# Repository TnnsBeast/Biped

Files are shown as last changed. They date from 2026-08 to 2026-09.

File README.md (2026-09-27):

# Beni

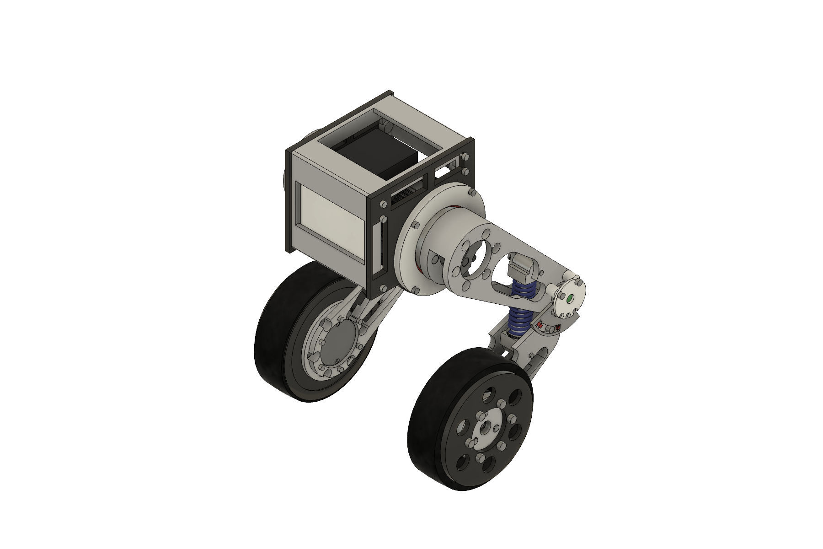
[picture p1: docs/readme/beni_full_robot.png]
Beni Prototype 1


A mostly 3D-printed wheeled biped moving to **Active-Knee Revision 2 (R2A)**:
active shoulder, remotely actuated belt-driven knee, and a driven wheel on each
leg. The current CAD gallery and assembled ABS leg show the legacy passive-knee
prototype. They remain the dimensional and failure-analysis baseline while the
new mechanism is designed.

**[Current status](PROJECT_STATUS.md)** · **[R2A plan](docs/design/active_knee_revision2_plan.md)** · **[Teardown evidence](evidence/reference/2026-09-25_beni_teardown/)** · **[Legacy mechanical design](beni_prototype1_design_record.md)** · **[Electronics](electronics/README.md)** · **[Firmware](firmware/README.md)** · **[Interactive viewer](web/)**

## Architecture direction

R2A removes the axial compression-spring cartridge. A knee actuator stays near
the shoulder/body and drives the knee through a synchronous belt inside the
proximal link. This keeps actuator mass out of the distal link and makes knee
angle, crouch, extension and landing response directly controllable.

The preferred Fusion study will compare a compact actuator mounted at the
proximal-link root with a stronger body-mounted actuator and shoulder-axis
jackshaft. The first layout uses one belt and is the simpler, lower-cost
prototype; the second keeps motor mass on the chassis. The actual knee motor,
belt family, ratio, output bearing stack and power architecture are not selected
yet. See the [dated actuator trade study](docs/design/active_knee_actuator_trade_study.md).
The project will not order or print around proportions inferred from the
teardown.

## Legacy mechanism and physical evidence

| Complete leg | Wheel motor and hub | Legacy passive knee |
|:---:|:---:|:---:|
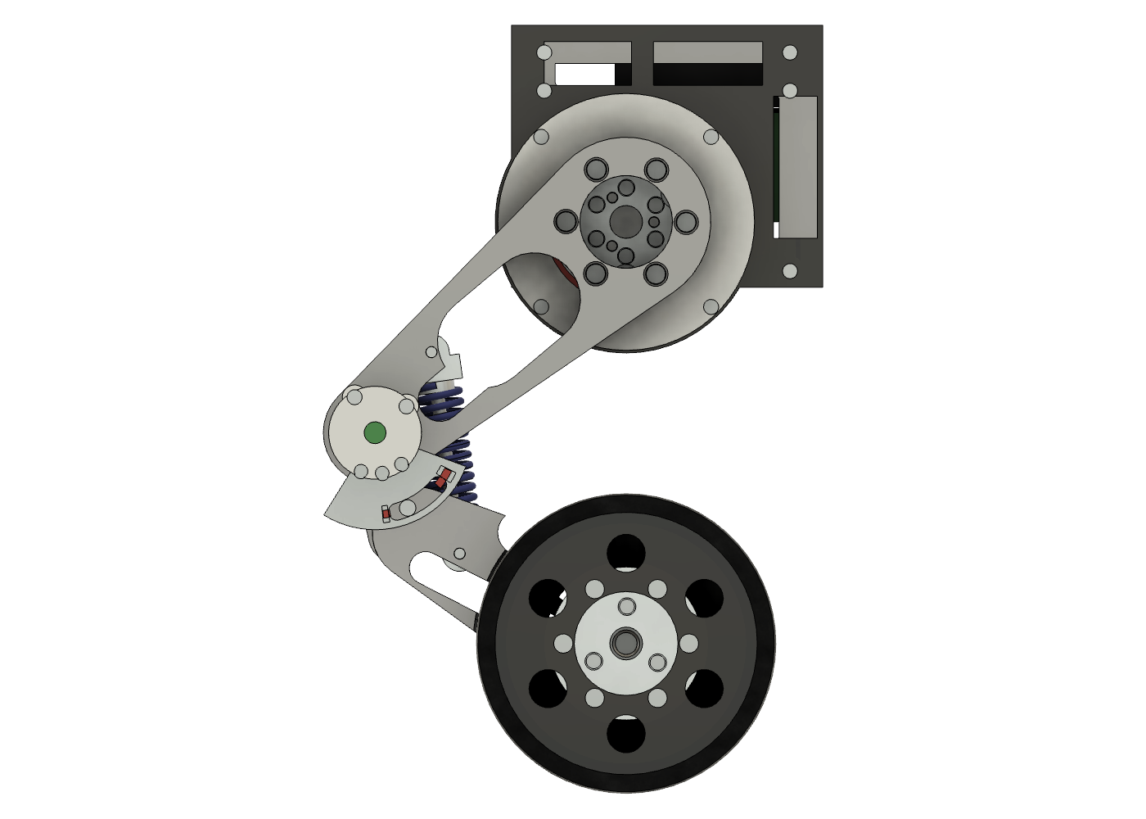
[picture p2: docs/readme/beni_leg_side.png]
Legacy complete Beni leg in Fusion
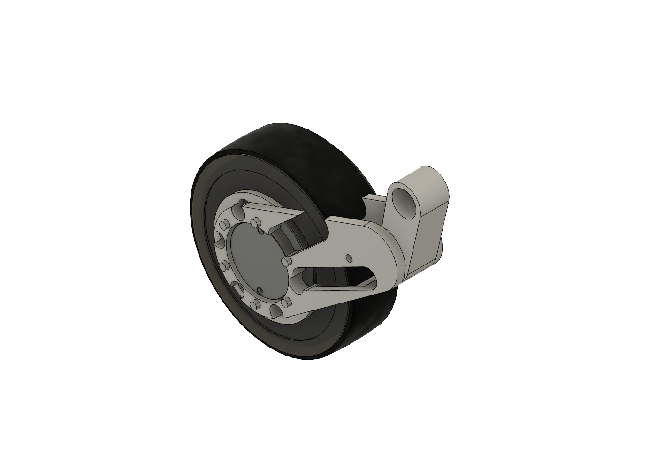
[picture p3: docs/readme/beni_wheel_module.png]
Wheel module with the motor housing fixed inboard and the output hub outboard
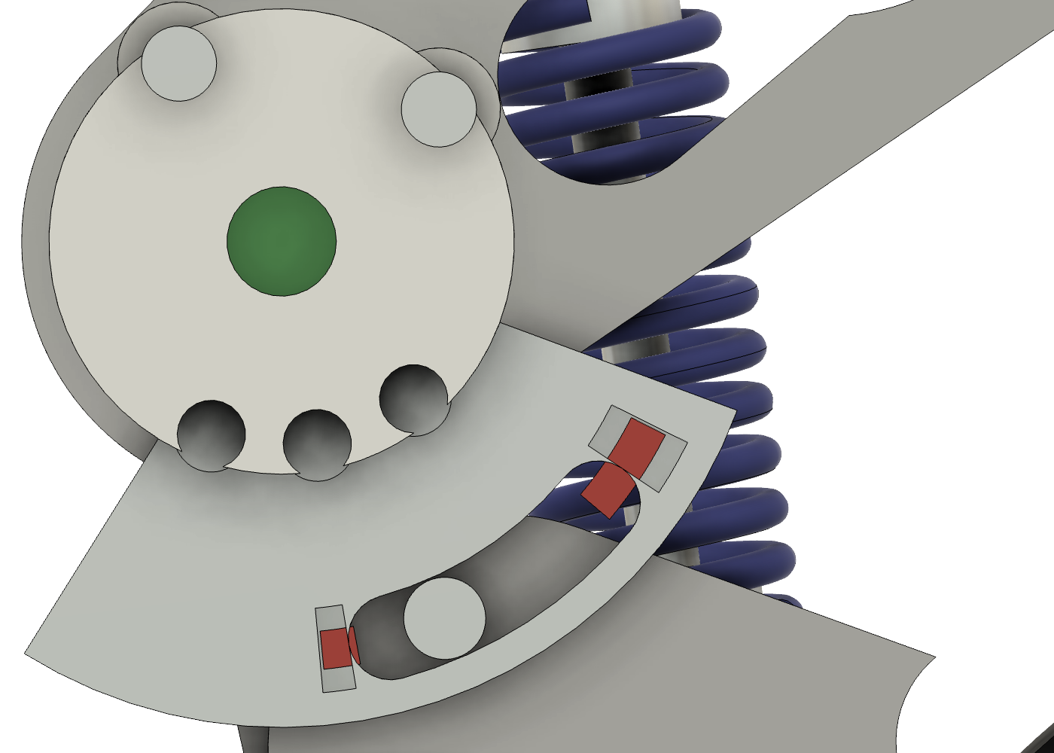
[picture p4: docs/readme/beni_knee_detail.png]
Legacy passive knee detail in Fusion
|  |  |  |

The owner printed and assembled the corrected shoulder hub, proximal link and
distal link. Most interfaces work, but the spring compresses on a curved path,
twists near both ends and escapes sideways. The unloaded guide is disengaged
and does not enter reliably during compression. Keep this article spring-free
and unpowered. The full observation is recorded in the
[failure evidence](evidence/assembly/2026-09-24_spring_escape/).

A frame review of the public teardown (September 27) shows Beni's knee driven
from the hip: a hip-coaxial crank moves the shin through a link, and a
body-fixed motor drives each hip ring through a short toothed belt. No belt runs
down the leg, so R2A's proximal-link belt is a project choice; comparing it with
a crank-and-link knee is an open decision. See the
[timestamped evidence note](evidence/reference/2026-09-25_beni_teardown/)
and the [R2A work plan](docs/design/active_knee_revision2_plan.md).

## Existing assembly references

The following documents describe the legacy article and remain useful for
accepted fit results, hardware inventory and assembly-path lessons:

- [Illustrated passive-article assembly manual](docs/assembly/ordered_pin_picture_guide.md)
- [Shoulder close-up](docs/assembly/shoulder_to_proximal_link.md)
- [Heat-set receiver picture map](docs/assembly/heatset_receiver_map.md)
- [Assembly verification gate](ASSEMBLY_VERIFICATION.md)
- [First-article evidence and archived print files](first_article_stl/README.md)
- [Manufacturing constraints](MANUFACTURING_CONSTRAINTS.md)

The CAD gallery is exported from the live Fusion model with
[`readme_images_fusion.py`](readme_images_fusion.py). It must be refreshed only
after a verified R2A Fusion model changes the displayed robot, leg, wheel or
knee views.

---

<!-- PRINT_QUEUE_START -->
## Current print queue — no R2A parts released

Automatically maintained convenience section for the active build.

**Do not print another passive-knee spring part.** No Active-Knee Revision 2
part or STL has been released. The next printable item will be an unpowered ABS
belt-transmission article after the motor layout, belt and pulley family, knee
output stack, service path and print orientation pass the Fusion release gates.

Keep the assembled legacy article spring-free and unpowered. Retain its parts,
owned actuators, bearings, pins and fasteners as evidence and possible reusable
hardware until the R2A BOM identifies them explicitly.
<!-- PRINT_QUEUE_END -->

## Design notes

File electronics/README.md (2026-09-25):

# Beni Prototype 1 — Electronics Design

**Revision 0 — 2026-08-09.** Originally written against
`beni_electronics_handoff_brief.md` §10. **That file no longer exists**: its
CAD-derived geometry survives as `00_mechanical_datum.md`, and its
request-for-design content is now answered by `01`–`07` themselves. Read §10
references below as pointing at `00_mechanical_datum.md`.
**[LEGACY FOR R2A]** The mechanical side described here was frozen and audited
for the four-actuator passive-knee robot. Active-Knee Revision 2 adds one knee
actuator per leg and invalidates the motor count, power budget, CAN topology,
harness, mass model and jump/landing controller. Use these documents as a
baseline only; do not place a new robot order until the knee motor and belt
ratio are selected in the
[R2A plan](../docs/design/active_knee_revision2_plan.md).

Every number here is traceable to either the CAD/design record (trusted), vendor
documentation (marked), or a calculation shown in-line (reproducible). Where a
figure could not be confirmed it is marked **[UNVERIFIED]** and appears in
`05_open_questions.md`. Do not order parts against an unverified figure.

## Reading order

| File | Covers | Brief §10 deliverable |
|---|---|---|
| `README.md` (this) | Decisions, §3 blockers, architecture | — |
| `01_power_and_battery.md` | Pack, power tree, budget, safety, regen | 1, 6, 7 |
| `02_harness_and_routing.md` | Clock spring, satellite node, connectors | 3, 4 |
| `03_compute_and_can.md` | Controller, IMU, CAN topology | 2, 5 |
| `04_firmware.md` | Plant model, LQR gains, jump/landing FSM, estimation | 8 |
| `05_open_questions.md` | Blockers, supplier questions, change requests | 10 |
| `06_logging_and_bringup.md` | Logging pipeline, 7-stage bring-up with gates | 9 |
| `07_bom.md` | Priced shopping list, ordered in three waves | — |

## The three §3 blockers — resolved

The brief says to resolve these before designing anything downstream. All three
now have answers, and **all three overturned an assumption baked into the BOM.**

### §3.1 Battery voltage — the brief blamed the wrong actuator

The brief assumed the GIM6010-8 shoulder sets the voltage ceiling. It does not.
The GIM6010-8 is a wide-input part (sources give 12–56 V, 15–60 V, or 12–72 V —
see `05_open_questions.md`). **The GIM4305-10 wheel actuator is the binding
constraint**: its SDC101 driver installation guide gives **12–36 V**, while
marketing copy claims 12–48 V and some reseller tables say 12–24 V.

The BOM's 4S pack (14.8 V nom) is too low regardless — a 4S pack cannot drive a
24 V-class actuator at rated performance, and the jump is power-limited.

**Decision: 6S LiPo (22.2 V nominal / 25.2 V full), with a 20 V buck feeding the
two wheel drivers.** The buck costs ~15 g and is deleted if Steadywin confirms
the 36 V rating in writing. This is the only option that is safe under *both*
the 24 V and the 36 V reading of the spec. See `01_power_and_battery.md` §2.

### §3.2 Battery physical size — cylindrical cells are out, and Z must open up

The CAD envelope is 69 × 25 × 45 mm = 77.6 cm³ at 250 g. A standard 4S 2200
LiPo is ~105 × 34 × 30 mm and 105 mm does not fit anywhere in the chassis.

Cylindrical cells fail on both axes: 6 × Molicel P26A 18650 is 275 g bare (over
the 250 g budget before assembly) and the 28 mm Z limit means the top-forward
box takes exactly **one** 18650. You need six and you can site two.

**Decision: GNB 6S 550 mAh "long type" (GNB5506S100AHV), 36 × 18 × 71 mm, 82 g,
12.2 Wh.** Near-exact match to the 36 × 28 × 72 mm top-forward box. It is a
**LiHV** pack — charge to 4.20 V/cell as ordinary LiPo, never 4.35 V.

Runtime is honest but short: ~18 min standing, ~10 min driving, ~13 min mixed.
**The single highest-value mechanical change available is opening chassis Z from
28 to 40 mm**, which allows 6S2P (2 packs, 164 g, 24.4 Wh) — double the runtime
and half the C-rate stress, still inside the mass budget. See `05_open_questions.md`.

### §3.3 Harness conductor count — the cavity constraint was misread

The brief treats the clock-spring cavity's 4.0 mm axial height as a *thickness*
limit and reasons about FFC. **It is a width limit.** In a clock spring the
bending curvature points radially, so bending strain is set by *radial*
thickness (12 mm available); the 4.0 mm axial dimension is the ribbon **width**
(~3.4 mm usable after slip sheets). A 20-way 1.0 mm-pitch FFC is 20+ mm wide and
cannot fit. At 3.4 mm you get 3 ways at 1.0 mm pitch or 6–7 at 0.5 mm.

**Decision: a satellite CAN node on the proximal link**, which drops the crossing
conductor count from 7–10 to **four** — V+, V−, CAN_H, CAN_L. The AS5048A then
runs full-rate SPI over a 40 mm PCB trace instead of 700 mm of cable next to a
motor. See `02_harness_and_routing.md`.

**Also corrected: the clock-spring wrap margin in the design record is wrong.**
§4.3 claims ~470° capacity / 27% margin from 400 mm of cable. Recomputing:

```
Δθ = L·(r_o − r_i) / (2π·r_i·r_o) = 400 × 11 / (2π × 20.5 × 31.5) = 1.084 turns = 390°
```

Against a 370° requirement that is **20° / 5% margin, not 27%.** Specify
**470–500 mm** of free spiral.

## Legacy system architecture [SUPERSEDED FOR R2A]

```
         6S LiPo 22.2V ──┬── fuse 30A ── P-FET soft-start ── XT30 loop key
                         │
              ┌──────────┼──────────────┬──────────────────┐
              │          │              │                  │
        shoulder L   shoulder R    20V buck ──┬── wheel L   │
        GIM6010-8    GIM6010-8               └── wheel R    │
              │          │                    │        │    │
          [CAN bus A: ODrive CANSimple]   [bus B]  [bus C]  │
              └────┬─────┘                    │        │    │
                   │                          │        │    │
              MAIN BOARD (STM32G474RET6, 84 × 60 × 1.0 mm, centre slot)
                   │                          │        │
                ICM-42688-P IMU        satellite L  satellite R
                                       (STM32G0B1 + AS5048A, proximal link)
```

**Three CAN buses, not one.** This falls out of two independent constraints that
happen to agree:

1. **Protocol.** The two actuators do not speak the same protocol. The GIM6010-8
   is an ODrive CANSimple derivative (`ID = node_id<<5 | cmd_id`); the
   GIM4305-10's SDC101 runs a proprietary "SteadyWin" or MIT protocol with its
   own master-ID scheme. Mixing them on one bus is possible but miserable.
2. **Bandwidth.** A single 1 Mbit classical bus cannot carry 4 nodes at 1 kHz —
   94% load typical, **108% worst-case** with bit stuffing. Neither actuator
   supports CAN-FD, so the FD escape hatch is closed.

The split — **A = both shoulders, B = left wheel + left satellite, C = right
wheel + right satellite** — lands every bus at 35–47% load, keeps each protocol
on its own wire, and matches the three FDCAN peripherals on an STM32G474RET6
exactly. It also means each clock spring carries only *its own* leg's bus, so
the 4-conductor crossing works with no sharing.

## Standing decisions

| Area | Decision |
|---|---|
| Bus voltage | 6S LiPo, 25.2 V full; 20 V buck for wheel drivers |
| Pack | GNB 6S 550 mAh long type, 82 g (2P if Z opens to 40 mm) |
| Controller | Custom 84 × 60 × 1.0 mm 4-layer, STM32G474RET6 |
| IMU | ICM-42688-P, 8 kHz ODR, AAF 250–500 Hz, decimate to 1 kHz *(rig: on-hand BNO085, **1 kHz raw** — it cannot stream 8 kHz)* |
| CAN | 3 × classical 1 Mbit, TCAN3414 transceivers *(rig: 2 × 500 kbps on Adafruit CAN Pal 5708 — TJA1051T/3, 3.3 V)* |
| Knee sensing | AS5048A on a satellite STM32G0B1CBT6 node, per leg |
| Control rate | 1 kHz (500 Hz floor) |
| E-stop | XT30 loop key (primary) + fail-safe soft stop + windowed WDT |
| Estimated mass | ~118 g against a 120 g budget — no margin |

## Four numbers in the brief that are wrong

Found while deriving the control design from `sim/beni.urdf` and
`sim/beni_inertia.json`. Full working in `04_firmware.md` §1.

| Brief | Actual |
|---|---|
| Unstable pole 9.7 rad/s | **11.20 rad/s** (τ = 89 ms). The LIPM formula drops body pitch inertia and the wheel reaction torque. |
| A 100 mm drop has ~10% energy margin on the knees | **It bottoms out.** The brief omits gravity work during the 50 mm of compression: 4.85 J demand vs 3.55 J capacity. Passive limit is ~49 mm for the two-leg robot (spring-rate method); the single-leg rig's 2-DOF figure is **45 mm** planning / **46.3 mm** at +24° (`../beni_single_leg_rig_design_record.md` §3). |
| Clock spring: 27% wrap margin | **5%** (§3.3 above). |
| Shoulders control ride height | **dRide/dθ_s = 0 at the nominal pose.** Zero height, damping and CBF authority at θ_s = 0. Fixed by a scissor stance. |

Consequence for the test plan: the brief's gate *"no powered jump until a 100 mm
drop never reaches +27°"* **cannot be passed passively.** It is replaced with a
49 mm passive gate plus a 100 mm gate run with the shoulder landing controller
live — see `06_logging_and_bringup.md` Stage 5, which now states the gate as
45 mm (the rig's planning limit).

Two further findings that are not brief errors but change the design:

- **The IMU datum pad is 195 mm above the wheel axis** — the worst location on
  the robot. At 20 rad/s² of pitch acceleration the lever arm produces 22° of
  apparent tilt against a 0.1° budget. Move it (CR-9).
- **A leg bounce mode at 3.66 Hz sits only 2.05× above the balance pole**, with
  ζ ≈ 0.01. Active shoulder damping is mandatory, not optional. *(3.66 Hz is the
  two-leg robot's 1-DOF figure. For the single-leg rig it is superseded: the rig
  is 2-DOF and predicts **3.49–3.63 Hz** — `../beni_single_leg_rig_design_record.md`
  §3.1.)*

## Status

All ten §10 deliverables are drafted across `01`–`06`. **They describe the
legacy four-actuator two-leg robot.** The legacy Mode A rig used a Teensy 4.1,
20 V bench supply and breadboarded buses; its carve-outs remain marked in `01`,
`02`, `03` §3, `06` and `07` Wave 0. R2A is the active design and requires a
fresh six-actuator electronics pass after knee-motor selection.

**Amended 2026-08-17 — the rig build is MODE A only.** The vertical slide, the
ballast and the drop series are deferred, which changes three things on the
electrical side:

| Change | Where |
|---|---|
| **Brake chopper [DEFERRED — MODE B]** — resistor, TLV3011, MOSFET, freewheel diode, sense divider **and heatsink** all out of Wave 0. Nothing generates regen with no drops. ⚠ Until it exists, **nothing may backdrive a motor** | `01` §7.2, `07` Wave 0 |
| **IMU gate re-scoped 8 kHz → 1 kHz raw** — the on-hand BNO085 tops out near 1 kHz on the SH-2 raw gyro report (100 Hz for calibrated/uncalibrated gyro), and its on-chip fusion carries 6.6 ms of latency, which alone would blow the <8 ms loop gate. Read raw, fuse on the Teensy | `06` Stage 0, `03` §4 |
| **Transceiver is the Adafruit CAN Pal 5708** (TJA1051T/3, onboard charge pump, single 3.3 V rail) — the TCAN3414 is surface-mount and this build is breadboarded. One board per bus | `07` Wave 0 |

**Owner scope 2026-09-02:** the complete single-leg integration article remains
ABS. Stages 0–1 and the wheel-clear/current-limited, self-weight-only subset of
Stage 2 are active, including unloaded phase-resistance, latency and CAN-soak
checks. The lever torque sweep, main-spring preload and
characterisation, ground traction, stall/proof loading, Stage 5 drops and all
later dynamic gates move to the two-leg PA-CF structural build. The detailed
boundary is in `06_logging_and_bringup.md`.

Nothing here has been
built or measured: every power figure is an estimate pending an inline watt
meter, the peak-power number swings ±40% on an unverified phase resistance, and
the wheel driver's maximum bus voltage — the one answer that decides the pack —
is still outstanding with Steadywin. **Read `05_open_questions.md` before
ordering anything.**

The shopping list is in `07_bom.md`. **Wave 0 (the Mode A rig) is now ~$25 of
electronics** plus a bench PSU; Wave A is ~$310 of two-leg dev hardware, and
Wave B is blocked on Steadywin.

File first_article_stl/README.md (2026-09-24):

# First print — actuator fit gates (ABS)

The four base files in [`actuator_fit/`](actuator_fit/) are the nominal
STEP-to-real-hardware gates printed on 2026-08-22.  Their results route the next
prints below.  The Mode A cable anchor in [`mode_a/`](mode_a/) is validated too,
but it is not needed to pass the motor-fit gate.

## Batch 1: printed and tested 2026-08-22

| STL | Checks |
|---|---|
| `ABS_FIT_GIM6010_HOUSING.stl` | shoulder housing clearance and 8 × M3 PCD74 clocking |
| `ABS_FIT_GIM6010_OUTPUT.stl` | shoulder output M3 pattern and the three Ø4 locating pins |
| `ABS_FIT_GIM4305_HOUSING.stl` | wheel-motor driver-cover clearance and 6 × M2.5 pattern |
| `ABS_FIT_GIM4305_OUTPUT.stl` | wheel output M3 pattern and Ø37.3 × 0.8 register pocket |

Owner-reported result: GIM6010 housing PASS; GIM6010 output pattern aligned but
its Ø4.05 printed pin bores did not hand-fit; the follow-up Ø4.15 pin-bore
coupon PASSed with a light press; GIM4305 housing PASSed with the real M2.5
screws; GIM4305 output PASS. The GIM4305 coupons are standalone, opposite-face
interface gauges and are not intended to nest. The failed GIM6010 output coupon
remains the evidence for the failed Ø4.05 result.

These were built and exported from Fusion document
`Beni_Prototype1_TestGauges` through the Fusion MCP.  Fusion's exact B-Rep
validation and source dimensions are in
[`actuator_fit/fusion_manifest.json`](actuator_fit/fusion_manifest.json).
Independent binary-mesh inspection found one closed manifold shell per file,
zero open/non-manifold edges, and zero degenerate triangles.

## Batch 1B: GIM6010 output-pin clearance diagnostic

The three generated files in
[`actuator_fit/gim6010_pin_trials/`](actuator_fit/gim6010_pin_trials/) retain the
validated three-pin pattern and change only the printed pin-bore diameter:
Ø4.15, Ø4.20 and Ø4.25 mm. The
[diagnostic README](actuator_fit/gim6010_pin_trials/README.md) gives the print
order, identification marks and pass rule. These are ABS calibration values,
not released PA-CF dimensions.

The Ø4.15 coupon passed on 2026-08-22, so stop there; the larger two trials are
not needed. Batch 2 is the unloaded ABS shoulder assembly in
[`assembly_dry_fit/`](assembly_dry_fit/). The original hub print proved the
motor interface but predated heat-set receiver design. Its replacement now
retains Ø4.15 and uses the owner-passed Ø5.3 M4 × 8 receivers. The owner has
printed it and successfully installed its inserts. The corrected proximal link
is printed and the owner confirmed all six hub screw seats on September 7.
The same folder contains
bed-ready shoulder-plate and cable-cover articles.

## 2026-09-04 owned-insert release

The owner confirmed the largest M4 × 8 ladder station, Ø5.3, passed all
installation and cooled-retention checks. Fusion incorporated it in both
saved documents. The two hubs and cable cover retain bed-ready ABS files in the
[receiver manifest](heatset_receiver_release_manifest.json). On September 14,
the owner selected Ø4.5 on the dedicated M3 ladder; the manifest, shoulder
plate, proximal link and stand exports now reflect that result.

The owner accepted the corrected hub's insert installation on 2026-09-05.
The **access-fixed Ø19.15 proximal link is printed with six-screw seating accepted**; use the final
[README print queue](../README.md#current-print--ordered-pin-unpowered-abs-mechanical-article). Two head
paths and one incomplete seat were corrected. The front cable post also now
mounts outside the cover. The final tyre-compatible wheel rim retains its
printability hold; the later no-tyre mechanical-test shell is separate.
[Current audit and acceptance](../evidence/assembly/2026-09-05_access_fix/).

## 2026-09-06 supported knee mock-up

The [temporary pin and provisional distal link](knee_mockup/) are printed and
provisionally assembled by owner report on September 7. Both spring caps are
also printed, with both spring ends seating flat uncompressed. Supported knee
movement and pin removal pass. [Photo and physical acceptance scope](../evidence/assembly/2026-09-07_owner_mockup/).
On September 15, the owner inserted a received metal pin into that provisional
shin. Its nominal Ø10 bore seized the pin, and the shin was broken to recover
it. The earlier loose Ø9.7 printed-pin result remains evidence, but the shin is
destroyed and must not be reprinted for another steel-pin trial. [Steel-pin
result](../evidence/knee_fit/2026-09-15_steel_pin_provisional_shin/).
The traveller remains scoped to two detached links supported on the bench;
the caps check the ends of the owned spring off the leg. Follow that batch's specific support
policy: **the distal mock-up needs selective supports**, while the pin and
caps print without supports. No main spring or motors attach to this mock-up.

## 2026-09-16 steel knee-pin bore result — Ø10.30 ABS selected

One received metal pin seated through both installed bearings and seized in the
provisional shin's nominal Ø10 ABS bore. The provisional shin was broken to
recover it. The owner printed the initial Ø10.05–Ø10.25 ladder
and found nominal Ø10.25 gives the intended firm-thumb fit through its 19.0 mm
station. The owner selected nominal Ø10.30, one 0.05 mm step above the physical
result, while the receiver was expected to span 21.6 mm. Fusion's final service
audit found that copied sleeve span trapped the link inside the bearing pockets,
so v26 confines the receiver to the clear 20.0 mm fork gap with 0.8 mm axial
clearance per side. Print the [released bed-ready distal fit article](assembly_dry_fit/ABS_FA_Distal_Link_L_D10p30_STEEL_PIN_FIT_PRINT_ORIENTED.stl)
and complete its physical insertion, withdrawal, spin, rock and axial-play
checks. The [21.6 mm full-span ladder](knee_pin_fit/) remains a conservative
optional diagnostic. Retention and encoder coupling still gate powered use.

## 2026-09-14 M3 receiver recalibration — Ø4.5 selected

The owner has printed the cable cover, corrected front cable post, wheel hub
and general fit gauge. [Exact files and completion record](../evidence/assembly/2026-09-07_small_parts_printed/).
The gauge's nominal Ø4.0 M3 station is too small.
[Physical result](../evidence/inserts/2026-09-14_m3_coupon_fail/). The owner
printed the Fusion-generated [Ø4.1–4.5 M3 ladder](insert_fit/) and selected the
largest, unmarked-end station, nominal Ø4.5. The active sources and exports were
promoted and verified through Fusion. Print the Ø4.5 corrected proximal-link
replacement and stand; print the Ø4.5 shoulder plate if the fitted plate is the
prior Ø4.0 revision. Detached motor-fit and cover/post/harness results are still pending;
the rear anchor is optional.
The [current print queue](../README.md#current-print--ordered-pin-unpowered-abs-mechanical-article) contains
the remaining prints, and [PROJECT_STATUS.md](../PROJECT_STATUS.md) maintains
the active mechanical, CAD and electronics work.

## 2026-09-17 unpowered spring-mechanical article

The new [mechanical spring test batch](mechanical_spring_test/) adapts the owned
OD18 / ID9 / 50 mm spring with two Ø8-pilot eyes, a removable square guide,
a -8°…+15° stop, an outboard steel-pin spacer/keeper and a support-free no-tyre
wheel shell. All seven STLs are print oriented and Fusion verified. The spring
is nominally uncompressed at -8° and reaches 10.240 mm modeled compression at
+15°. Use only with both motors unplugged, the stand clamped, the wheel clear
and the distal side hand-contained. The local README is the required print,
detached-fit, assembly and observation traveller.

This release does not clear the final tyre-compatible rim, final knee-pin
retention, encoder coupling, spring characterisation, ground contact or powered
motion. It depends on the Ø10.30 distal article passing its physical steel-pin
checks first.

## 2026-09-22 ordered-pin fit ladders

The two [ordered-pin ABS ladders](ordered_pin_fit/) are complete historical fit
evidence. Using the actual pins without measurement, the owner selected
nominal Ø4.25 for the root-dowel hub socket and nominal Ø4.25 for the clevis
link passages. Fusion v29 now contains those values and the large
[hub/proximal/distal production files](ordered_pin_integration/) were
re-exported and released for printing. The Ø6 × 10 captive stop remains a
deliberate Ø6.2 clearance fit and has no ladder. **[SUPERSEDED 2026-09-23:
the v29 distal export lost its Ø10.30 receiver, and the owner then requested
Ø4.30 root-dowel and clevis-link holes. Print the PINREV2 hub and links from
the [current queue](../README.md#current-print--ordered-pin-unpowered-abs-mechanical-article);
[audit](../evidence/assembly/2026-09-23_mechanical_reprint_audit/).]**

## Actuator-coupon slicer setup

- Material: the owner's normal, tuned **ABS** profile in an enclosure.
- No scaling and no hole compensation for the first pass.  The purpose is to
  measure the printer/material result, not hide it.
- 0.20 mm layers, 4 walls, 5 top and 5 bottom layers, 30% infill.
- Print every coupon exactly as exported: largest circular face on the bed.
- No supports.  Add a brim only if this ABS/printer combination normally warps.
- Keep the four parts labelled in the slicer or print them one at a time; the
  two housing rings are easy to confuse after removal.

## Test without calipers

Use the delivered actuator, its real screws and its real locating pins as the
go/no-go fixture.  Do not drill, file, sand, heat or force the coupon before the
first result is recorded.

1. Place the matching coupon on the interface by hand.  It must reach the
   mating face without rocking or being hammered.
2. Start two opposite screws with fingertips only.  They must both enter the
   threads without bending the coupon or pulling it sideways.
3. Check the remaining holes with loose screw shanks.  For the GIM6010 output,
   all three factory pins must enter together; do not tap them in.
4. Photograph the seated face and any obstruction.  Record whether the failure
   is the centre/register, bolt circle, pin circle, or hole clearance.
5. Remove the coupon.  A print that needed screw torque to seat is a **fail**,
   even if it eventually went flat.

A clean hand fit releases the corresponding ABS leg interface for the next
print. The GIM6010 output requires the smallest passing Batch 1B bore before
that release. No ABS result transfers to PA-CF: repeat the critical interface
coupon immediately before the later two-leg structural prints.

## Optional Batch 2: Mode A cable anchor

`mode_a/RIG_Cable_Anchor_ModeA.stl` is a 4 mm non-rotating strain-relief anchor
for the GIM6010 rear face.  Place either 41.0 × 15.45 mm broad face on the bed
(rotate 90° about X in the slicer), use the same ABS profile, and install with
2 × M3 × 8 SHCS plus washers.  It has 1 mm radial clearance around the STEP's
Ø57 driver cover and showed zero modeled interference in the complete rig.

Do not energise or backdrive either actuator as part of this fit test.  The
delivered connector pinouts are not fully verified, and the bench supply cannot
sink regenerative energy.

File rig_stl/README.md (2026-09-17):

# Rig parts to print

Exported from the verified `Beni_SingleLegRig` assembly at High mesh refinement.
All STLs are in millimetres and sit at their **assembly coordinates**, not
centred on the origin — every slicer will drop them to the bed and centre them.

Companion: `../beni_single_leg_rig_design_record.md`.

> ## ⚠ HOLD `reroute/Distal_Link_L.stl` — 2026-09-01 DFM audit
> The proximal-link print failure exposed a reversed unequal-circle tangent
> sign in the shared source helper. The source geometry is corrected, but the
> existing distal STL predates that correction and its wheel-end boss needs a
> separate exact support/overhang check. Do **not** print this legacy distal STL.
> The verified Ø10.30 × 20.0 mm ABS fit article is now released separately at
> [`../first_article_stl/assembly_dry_fit/ABS_FA_Distal_Link_L_D10p30_STEEL_PIN_FIT_PRINT_ORIENTED.stl`](../first_article_stl/assembly_dry_fit/ABS_FA_Distal_Link_L_D10p30_STEEL_PIN_FIT_PRINT_ORIENTED.stl).
> The other flat-datum parts in this directory are unaffected.

> ## ⚠ OWNER SCOPE 2026-09-02 — COMPLETE ABS SINGLE-LEG INTEGRATION FIRST
> The current print campaign stays ABS through the complete single-leg
> integration article. The motors may be commissioned only with current limits,
> the wheel clear, and no load beyond self-weight. PA-CF, the torque arm,
> spring-characterisation, ground traction, stall/proof and drop loading are
> deferred to the later two-leg structural build. Existing PA-CF settings and
> load calculations below remain the structural-build specification, not the
> current print order.

> ## ⚠ AMENDED 2026-08-17 — MODE A ONLY
> The build is **Mode A**: the shoulder bolts rigid to a printed stand. The
> vertical slide, the ballast and the drop series are **deferred, not cancelled**.
>
> | Active Mode-A set (individual release gates still apply) | Active design holds | Deferred |
> |---|---|---|
> | `RIG_Stand` with owner-selected Ø4.5 M3 receivers, the separately released Ø10.30 distal fit article, `RIG_Knee_Stop_Plate_L`, `RIG_Knee_Bumper_Tube_L`, `RIG_Knee_Magnet_Carrier_L`, and the cartridge-eye reroute parts | Distal physical fit, pin retention and encoder coupling. M4 hubs: Ø5.3 ABS coupon passed; use the first-article files. `Wheel_Rim_L`: unsupported-ledges printability hold. Proximal root: replace the printed Ø4.0 link with the released Ø4.5 revision before M3 installation. `RIG_Knee_Collar_L`: no pin retention. `RIG_Cable_Post_A`: use the revised cover-mounted ABS first article. `RIG_Cable_Post_B`: Mode-A redesign. | `RIG_Torque_Arm`, `RIG_Floor_Plate`, §1 `RIG_Carriage`, §2 `RIG_Index_Bar`, §8 `RIG_Ballast_Pot` ×2, `RIG_Rail` / blocks / Ø8 mode pin / bumpers, and every loaded PA-CF test article. |
>
> `RIG_Stand` replaces `RIG_Carriage` as "the part everything else hangs on", and
> the overhang it works at is **42.00 mm, not 63.00** — Mode A deletes the block
> and the carriage from the lateral stack, so the stand's outboard face *is* the
> motor front mount face. Its requirement set is in
> **`../fusion_agent_guide_mode_a.md`**; the short version is 11.00 N·m of shoulder
> yaw stall / 25.00 N·m proof, and **it must be clamped to the bench, not
> weighted.**

---

## Settings — the same for every part here

Per `beni_rig_no_machining.md` §1. **Orientation is the strength lever; infill is
not.** PA-CF measures 84–102 MPa in XY but only 26–50 MPa in Z, so which way the
part lies on the bed decides whether it survives.

| Setting | Value | Why |
|---|---|---|
| Perimeters / walls | **5** | shells carry bending load; this is the main lever |
| Infill | **40 % gyroid** | past ~40 % the returns collapse. 100 % adds time and warp, not strength |
| Layer height | 0.15 mm | more interlayer bonds per mm of Z |
| Extrusion temp | **top of range** | layer adhesion is temperature-driven |
| Cooling | **minimal** | fast cooling is the #1 cause of weak Z bonds |
| Filament | **dried** | non-negotiable; wet nylon loses a large fraction of interlayer strength |

Structural release material remains **PA-CF**, but that release is deferred to
the later two-leg build.

**The complete single-leg integration campaign is ABS.** Print
`GAUGE_Fit_Coupon`, negative motor
mating coupons or the actual mating parts, assembly-rehearsal parts,
cable-routing parts, covers, floor-contact parts, and the whole unloaded
single-leg article in ABS. The two existing `GAUGE_*_Motor_Interface` files
are positive motor stand-ins and are optional now that the motors are in hand.
Motor commissioning is limited to wheel-clear, current-limited, short slow
commands under self-weight. Do not apply torque-arm load, stall torque, main
spring preload/characterisation, ground traction, drops, or proof loads through
the ABS path. `RIG_Stand`, both hubs, `RIG_Torque_Arm`, and the two cartridge eyes
remain PA-CF for later loaded testing. An ABS coupon calibrates only the ABS
campaign; repeat critical coupons immediately before the two-leg PA-CF prints.
See `../beni_rig_no_machining.md` §4 for the load-path reasoning.

---

## Print in this order

### 0. First — `../print_stl/GAUGE_Fit_Coupon.stl`
Unchanged from the robot build, and it still de-risks every print here. Six
critical bores in one 26 × 92 × 8 bar. For the ABS campaign, test each bore with
the real matching fastener or dowel and record which nominal feature gives the
required fit. The result is material-, printer-, orientation-, and
profile-specific; do not reuse the ABS result later as PA-CF compensation.

The two `GAUGE_*_Motor_Interface.stl` files were re-measured against design
record §2 and every feature agrees, but they are positive stand-ins. They are
optional now that the motors are present and cannot perform the new physical
mating check. Use a negative ABS coupon or the actual ABS mating part instead.

For the current GIM6010 ABS article, do **not** use the nominal
`reroute/Shoulder_Output_Hub_L.stl`. The owner-tested Ø4.15 ABS variant and the
exact next-print sequence are in
[`../first_article_stl/assembly_dry_fit/`](../first_article_stl/assembly_dry_fit/).
That compensation is specific to the ABS profile and is not a structural
release dimension.

### 1. ~~`RIG_Carriage.stl`~~ — **[DEFERRED — MODE B]**
90.2 cm³, **103.7 g**, 154 × 170 × 8. Do not print this for the Mode A build; it
exists only to ride the MGN12 blocks. **`RIG_Stand` takes its place** and inherits
the two things below that were never about the slide:

- **The five-hole panel interface is unchanged.** Whatever mounts the motor must
  line up with `Chassis_Shoulder_Plate_L`'s existing frame-bolt holes at
  (−60, −18), (−60, 48), (−60, 62), (30, 48), (30, 62). Verified concentric in CAD;
  confirm on the print before installing inserts.
- **The deferred source records the intended topology.** Its builder now inherits five
  Ø4.5 × 6.0 M3 pockets and
  four full-depth source-updated Ø5.3 M4 receivers for the owner-held M4 × 8
  inserts. The stripped carriage was not rebuilt or released. Do not print it
  for Mode A; repeat the coupon for its eventual material/profile and rebuild it
  through Fusion when Mode B returns. The canonical
  disposition is in
  [`MANUFACTURING_CONSTRAINTS.md`](../MANUFACTURING_CONSTRAINTS.md#threaded-interfaces-in-printed-parts).

The Mode B notes, for whenever the slide gets built: plate face flat on the bed so
the 63 mm overhang bends in the print plane and the eight block-screw counterbores
print as pockets; no support anywhere, every hole a through-feature.

### 2. ~~`RIG_Index_Bar.stl`~~ — **[DEFERRED — MODE B]**
114.3 cm³, 131.4 g. Indexes drop height on the slide, and Mode A runs no drops.
When built: flat on the bed, station holes vertical — the Ø8 pin bears across
layers, not along them. 17 stations at 10 mm pitch. Not on the slide, so its mass
does not matter.

### 3. `RIG_Floor_Plate.stl`
260 × 60 × 6, flat on the bed. **A 6 mm aluminium plate is the better part** if
you have one — the wheel rolls on this and the brief wants it flat and hard. The
STL is provided so the rig can be finished without a metal supplier. **Still
needed in Mode A**: it is what the wheel rests on, and it is what stops the leg
falling when the shoulder is de-energised.

### 4. `RIG_Knee_Collar_L.stl` and `RIG_Knee_Magnet_Carrier_L.stl`
Tiny, but the second one is an instrument mount.

- **Do not print or use `RIG_Knee_Collar_L.stl`.** Fusion inspection found that
  its 3 mm collar does not overlap the modelled Ø10 pin and its Ø2.5 hole runs
  axially rather than radially, so it cannot be the claimed set-screw
  retention. The 35 mm pin allocation also leaves no proven free shaft for an
  off-the-shelf clamp collar. Re-design retention only after the delivered
  eBay pin and the real bearing/link stack are measured.
- Print `RIG_Knee_Magnet_Carrier_L` with its bore axis vertical, so its Ø10
  locating fit is round.
- `RIG_Knee_Magnet_Carrier_L` carries the **0.05 TIR** concentricity that keeps
  the AS5048A honest. **Measure it on a dial indicator.** If runout exceeds
  ~0.1 mm, bond the magnet into the pocket using the Ø10 bore as the datum
  instead of trusting the printed step.
- The magnet bottoms on the dowel pin's own ground end face at y = 93.7, so the
  pocket depth is not what sets the air gap.

### 5. `RIG_Torque_Arm.stl`
93.6 cm³, 107.6 g. **Flat on the bed, arm plane parallel to the bed**, so the
200 mm bending load is fully in-plane. Bolts to the hub's 6 × M4 Ø44 PCD **in
place of the proximal link** — step 2 runs with the leg off.

### 6. `RIG_Cable_Post_A.stl`, `RIG_Cable_Post_B.stl`
Post A was redesigned on 2026-09-05 to sit **outside the cover**, with an
open Ø8 tie eye beyond the cover edge. Use the supplied orientation in the
[bed-ready ABS file](../first_article_stl/mode_a/ABS_FA_RIG_Cable_Post_A_COVER_MOUNT_PRINT_ORIENTED.stl),
quantity 1, no supports. Two **M3 × 12** replace the upper cover M3 × 10;
the lower cover screws remain ×10 and all eight motor-housing screws stay ×8.
Fit panel/stand bolts before the post. The prior housing-mounted STL and its
M3 × 16 instruction are superseded. [Acceptance and paths](../evidence/assembly/2026-09-05_access_fix/).

⚠ **`RIG_Cable_Post_B.stl` is NOT printable for Mode A — do not send it to the
bed.** [BLOCKED 2026-08-20] The part mounted to `RIG_Column`'s T-slot, and
`strip_mode_b()` deleted the column, so the occurrence is no longer in the model.
`build_rig_cable_post_b()` (`rig_lib.py:735`) is intact but is still dimensioned
off the Mode B constants `RAIL_X`, `COL_Y0` and `TRAVEL_UP`, so the STL in this
directory (dated 2026-08-12) is geometry for a fixture that no longer exists. It
needs re-dimensioning against `RIG_Stand` before it is printed or re-exported.
Not redesigned here — it is a design decision about where the cable is anchored
now that the column is gone.

### 7. The knee stop parts
- **`RIG_Knee_Stop_Plate_L.stl`** — PA-CF, flat on the bed. Replaces the laser-cut
  steel arc. Bolts to the same three M3 inserts in the proximal arm-B boss with
  M3 × 6. Carries the −8° extension stop (3.9 MPa, printed conformal slot end) and
  a +28° flexion backup.
- **`RIG_Knee_Bumper_Tube_L.stl`** — **TPU 95A**, bore axis vertical. A sleeve that
  goes *around* the washer stack, not on top of it: the two must act in parallel
  or the steel never goes solid. Print at 3 walls so its rate stays soft.
- The +27° hard stop itself is bought: **16.571 mm of M5 washers** on the guide
  rod, bulked with 1.0 mm plain washers and trimmed with 0.2/0.3/0.5 mm DIN 988
  shim washers. **Set it after step 6, from the measured spring** — one 1.0 mm
  washer moves the stop by 1.83°.

### 8. ~~`RIG_Ballast_Pot.stl` × 2~~ — **[DEFERRED — MODE B]**
Open side up, no support. Fill with steel shot, airgun BBs or a jar of M4 nuts and
weigh on a kitchen scale — 344 g of capacity across the pair, and only ~37 g is
needed to hit 1.645 kg with a 500 g motor. **Mode A has nothing to ballast**: the
1.645 kg figure is the sprung mass on the slide, and there is no slide. Do not buy
the shot yet. This is also why conflict C4 (motor mass 388/150 vs 500/250 g) stops
being a rig-design risk — it was only ever deciding how much shot went in here.

### 9. `RIG_Stand.stl` — **the Mode A part**
Modelled 2026-08-17 by `rig_lib.build_rig_stand()`. **499.3 cm³, 574.2 g**,
200 × 32 × 299.3 (X × Y × Z), one body. Full requirement set:
**`../fusion_agent_guide_mode_a.md`** §2.

**Exported 2026-08-20** to `RIG_Stand.stl` (binary, MeshRefinementHigh, 2372
triangles). Measured from the model against the figures above: 499.3082 cm³,
574.2045 g, 200.0000 × 32.0000 × 299.3119, mount face y = 42.0000. Mesh bbox
reproduces the B-Rep to 0.0000 mm; mesh volume is +0.020 % from chordal
tessellation of the bores. Snapshot: `../snapshots/2026-08-20_rig-mode-a/`.

**Orientation: mount face (y = 42.00) flat on the bed, building inboard.** No
support anywhere, and the part's Y thickness only ever decreases away from the
bed (12 mm web, 32 mm foot, both sharing the y = 42.00 face).

- **Orientation follows the load, and the load is torsion, not bending.** The
  dominant case is the shoulder's own reaction: **11.00 N·m yaw at stall, 25.00
  N·m proof**, against 2.30 N·m pitch and 2.99 N·m roll. Yaw is a couple about Y,
  i.e. a couple lying *in* the XZ plane, and every layer of this print is an XZ
  slice — so the whole dominant load stays in the plane where PA-CF is 84–102 MPa
  instead of 26–50. Printed upright the same couple would try to peel layers.
- **The bed-facing face is the one that has to be flat.** It bears on
  `Chassis_Shoulder_Plate_L`'s inboard face over the five bolt landings, and the
  five insert bores open on it, so they print as clean first-layer holes with no
  bridging. The released bores are **Ø4.5 × 6.0** for 5 mm Voron-style M3
  inserts, with 1 mm installation space and a 6 mm printed floor. The owner
  selected Ø4.5 on the same-profile ABS ladder; Fusion verified and re-exported
  the stand after promotion.
- ⚠ **Footprint is 200 × 299 mm, so it needs a bed ≥ 300 mm in one axis.**
  **RESOLVED 2026-08-20: the printer is a Bambu Lab H2S, build volume
  340 × 320 × 340 mm** (vendor spec, web, 2026-08-20 — the first build envelope
  recorded in this repo). `RIG_Stand` **fits outright in the orientation above**;
  the splice contingency below is not needed and is retained only in case the
  part is ever built on a smaller machine. The 299.3 mm is not negotiable — it is
  227.31 mm of ride height plus the pad up to the panel's top edge — and it is
  the *smallest* dimension of the three, so no other orientation fits a smaller
  bed. If a printer cannot take it, split it low in the column where the section
  is largest and splice with a bolted lap; do **not** split near the mount pad.
- **Overhang is 42.00 mm** from the stand's outboard face to the wheel plane.
  ⚠ Anything you shim in between — a washer, a spacer, a printed pad — scales all
  four moments. Verified 42.000 mm in CAD with a 0.000 mm gap to the panel.
- **It must be clamped, not weighted.** 11.00 N·m needs 11.2 kg of hold-down at a
  100 mm base half-width, 7.5 at 150, 5.6 at 200, 4.5 at 250, 3.7 at 300. This
  stand is 0.574 kg. **Four clamp landings** are modelled on the foot's top face
  (X −100…−77.5, **−32.0…−8.5** [CORRECTED 2026-08-20 — was recorded −43.5…−8;
  measured 23.5 mm, not 35.5. Still over the 20 mm minimum, so check 7 passes],
  +8…+61.5, +77.5…+100, each 32 mm wide in Y), plus
  **4 × M6 bench-bolt holes** at **X = −88, −26, +34, +88** — Ø6.5 through with
  Ø11 × 7 counterbores so the heads sit sub-flush and the landing still takes a
  jaw. ⚠ **The bolt set is asymmetric.** This row previously read "X = ±88 and
  ±26"; the built part has its third hole at **+34, not +26**. Source of truth is
  `rig_lib.py:1625`, `STAND_BOLT_X = (-88.0, -26.0, 34.0, 88.0)`, confirmed
  against the model 2026-08-20. Drill from the STL or from that constant, not
  from a symmetric assumption.
  Buy the clamps — the Mode A build needs more of them than Mode B did.
- **Shoulder axis ≥ 221.31 mm above the floor plate** — that is the ride height at
  the −8° extension stop, i.e. where a free leg actually rests. ⚠ Met by dropping
  the **bench plane** to Z = −227.31 and putting `RIG_Floor_Plate` on it, *not* by
  a stand height: the shoulder axis is the model origin. The floor plate's old
  Z = −209.269 top face is the φ = 0 contact plane and is 12.04 mm too high for
  Mode A. See `build_rig_floor()`.
- Same five-hole panel interface as §1, but do not print or install inserts from
  the current STL. Rebuild the five bores to the verified Voron-style pocket in
  Fusion first; the 12 mm web preserves a deep floor after correction.

---

## `reroute/` — formerly machined, now printed

These five were 7075 or steel in `archive/manufacturing/machined_parts_spec.md`. Routing
per `beni_rig_no_machining.md` §2. **Print one of each and dry-fit before
committing to a second set.**

| File | Was | Orientation | The thing that will bite |
|---|---|---|---|
| `Shoulder_Output_Hub_L.stl` | 7075-T6 | flange face flat on the bed | **USE THE NEW ABS FIRST ARTICLE**, not this nominal coordinate file. The [print queue](../README.md#current-print--convenience-link) links the Ø4.15 motor-pin / Ø5.3 M4 receiver version. The owner accepted the corrected hub's insert installation. Retain it and rehearse the new access-fixed proximal link. PA-CF remains deferred. |
| `Wheel_Hub_L.stl` | 7075-T6 | flat, register face up | **ABS FIRST ARTICLE READY:** use the new bed-ready Ø5.3 file in the [receiver map](../docs/assembly/heatset_receiver_map.md). Install M4 × 8 inserts from the detached motor face, with 2 mm projection. Rim printing remains held for unsupported ledges. |
| `Cart_Upper_Eye_L.stl` | 7075-T6 | **pivot bore axis vertical** | Printed on its side the eye splits along a layer. Carries the **11.00 ±0.05** pivot-to-spigot dimension: **measure what you actually achieved and feed the real number into the spring model** rather than chasing nominal. Step 6 measures F₀ and k anyway, so a print error is detectable. |
| `Cart_Lower_Eye_L.stl` | 7075-T6 | pivot bore axis vertical | Same, for **14.57 ±0.05** including 2.0 mm of shims. |
| `Distal_Link_L.stl` | PA-CF design; next article ABS | **HOLD — this legacy file remains unreleased; use the separate first article** | This STL predates the tangent correction and Ø10.30 receiver. Fusion v26 now uses a serviceable Ø10.30 × 20.0 mm receiver and passed printability, support-removal, assembly/service and mesh checks. Print the [bed-ready ABS fit article](../first_article_stl/assembly_dry_fit/ABS_FA_Distal_Link_L_D10p30_STEEL_PIN_FIT_PRINT_ORIENTED.stl) with its selective-support policy. Physical fit, retention and encoder coupling remain open. |

`Knee_Stop_Arc_L` is **gone entirely** — there are no laser-cut parts. The +27°
crash stop moved into the spring cartridge as a compression stack (a stack of
bought M5 washers plus a printed TPU sleeve), and `RIG_Knee_Stop_Plate_L` is a
printed part that keeps only the −8° extension stop and a +28° backup. Full
reasoning and the verification sweep are in the design record §8.

---

## Reused unchanged from `../print_stl/`

`Proximal_Link_L` · `Wheel_Tyre_L` (TPU 95A) ·
`Knee_Encoder_Bracket_L` (ABS) · `Chassis_Shoulder_Plate_L`.

`Wheel_Rim_L` is no longer in this list: the owned M4 × 8 redesign adds six
Ø6.0 × 2.2 reliefs for the insert ends that project 2.0 mm from the wheel hub.
The other four remain unchanged.

---

## What the first-article campaign validates

- Every bore fit and the ABS slicer compensation (`GAUGE_Fit_Coupon`).
- Both real motor interfaces using negative ABS mating coupons or the actual ABS
  mating parts. The existing positive motor stand-ins remain useful for CAD-side
  checks but do not fit onto the delivered motors.
- That **the stand's** five insert bores match the panel. ~~and its eight block
  screws match the MGN12H 20 × 20 pattern~~ — **[DEFERRED — MODE B]**, there are no
  blocks.
- **The stand's clamp access and flat seating**, without applying meaningful
  torque to the ABS article. The loaded hold-down release test is deferred to
  the later PA-CF structural stand: clamp it to the bench, then push at the
  wheel with a luggage scale to make ~11 N·m about the shoulder axis (≈52 N at the
  209 mm nominal lever) and confirm nothing lifts, slips or visibly twists. This
  is the one Mode A check with no CAD equivalent, and it is the check that decides
  whether the whole build is trustworthy.
- **That the nominal 42.00 mm overhang assembles correctly.** The value comes
  from the STEP/Fusion stack. Without calipers, fully seat the motor and panel,
  confirm every mating face closes, and verify the wheel plane lands correctly
  over the floor plate. Every moment in the load table still uses the 42.00 mm
  CAD datum.
- The knee stack only after the received pin passes separate bearing checks and
  a corrected full-depth ABS bore coupon: Ø10 dowel through both 6800s,
  pressed into the printed distal boss, and magnet carrier on. **Axial
  retention remains unreleased; do not substitute the existing collar STL.**
- **Assembly order.** ~~The eight carriage-to-block screws are captive under the
  panel, so the order is: carriage → blocks → panel + motor.~~ **[DEFERRED — MODE
  B].** Mode A is simpler — stand → panel + motor → leg — but the same rule
  applies: confirm you can reach every fastener before the motor goes on, because
  the panel hides whatever is behind it.

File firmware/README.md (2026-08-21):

# Firmware

The first implementation is the non-energizing Teensy 4.1 bench scaffold in
[`teensy_stage0/`](teensy_stage0/). It deliberately stops before any actuator
protocol. Hardware gates and the later control architecture remain canonical in
[`electronics/06_logging_and_bringup.md`](../electronics/06_logging_and_bringup.md)
and [`electronics/04_firmware.md`](../electronics/04_firmware.md).

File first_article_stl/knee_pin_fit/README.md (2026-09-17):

# Optional ABS knee-pin full-span diagnostic ladder

The received metal pin seized in the provisional shin's nominal Ø10 printed
bore. The owner then tested an initial Ø10.05–Ø10.25 ladder whose stations were
19.0 mm deep. Nominal Ø10.25 accepted the pin with firm thumb pressure, which
is the intended fit feel.

The first Fusion inspection assumed the printed receiver would copy the former
steel sleeve's **21.6 mm** span: the Ø22 center boss runs from Y=65.0 to 84.0
and its Ø16 thrust lands continue to Y=63.7 and 85.3. This ladder intentionally
covers that conservative span and starts at the owner's Ø10.25 candidate.

The later service-path audit found that a 21.6 mm integrated receiver overlaps
both bearing pockets and cannot enter or leave the assembled fork. The released
v26 link therefore uses a **20.0 mm** receiver in the clear Y=64.5–84.5 fork
gap, leaving 0.8 mm clearance per side. This 21.6 mm ladder remains useful only
as a conservative diagnostic if the released Ø10.30 link prints too tightly.

The owner subsequently selected **Ø10.30** for the production ABS source: one
0.05 mm step above the firm-thumb Ø10.25 result. Printing this second ladder is
therefore optional. Retain it for diagnosis if the first Ø10.30 link is tighter
than expected; it is not in the active print queue.

## Print

[Download the corrected print-oriented STL](ABS_CAL_KNEE_PIN_BORE_LADDER_PRINT_ORIENTED.stl).

- Quantity: 1
- Material/profile: the same tuned enclosed ABS profile used for the active leg
- Layer height: 0.20 mm
- Walls: 4
- Top/bottom layers: 5 / 5
- Infill: 30%
- XY hole compensation: 0
- XY contour compensation: 0
- Supports: off
- Orientation: import unchanged; the thin runner and index tab are on the bed,
  and all five pin bores are vertical

The two small holes mark the **Ø10.25 end**. Moving away from them, the five
stations are:

| Station from marked end | Nominal bore |
|---:|---:|
| 1 | Ø10.25 mm |
| 2 | Ø10.30 mm |
| 3 | Ø10.35 mm |
| 4 | Ø10.40 mm |
| 5 | Ø10.45 mm |

Station 2 matches the owner-selected Ø10.30 ABS source. The other stations are
diagnostic alternatives; none transfers to PA-CF.

## Test

1. Inspect the recovered pin for scoring or a raised end burr. Do not sand its
   ground journal. Use one pin for every station.
2. First pass that pin through each 6800 bearing separately, without the shin.
   It must insert and withdraw under controlled thumb pressure. Stop and report
   if either bearing needs impact or clamp force.
3. Test the ladder dry and at room temperature, starting at the two-hole
   Ø10.25 end.
4. Push only with your fingers. Stop a trial as soon as force rises sharply.
   The 35 mm pin remains 13.4 mm exposed through the 21.6 mm coupon, so withdraw
   or push it back using the exposed ends. Do not hammer it into a station.
5. Select the **smallest** station that accepts controlled thumb pressure,
   does not spin freely in the boss and remains removable. Report the station
   number and whether the cooled pin spins, rocks or pulls out by hand.

If every station is too tight or the pin becomes trapped, break only that coupon
boss and report the last attempted station. Use the separately released
Ø10.30 × 20.0 mm distal fit article for the active physical test.

## Verification

Fusion MCP built and inspected one closed diagnostic solid with exact Ø22 × 21.6 mm
stations and bores Ø10.25–Ø10.45 in 0.05 mm steps. The print-oriented
high-refinement STL is a closed, non-degenerate manifold at Z=0. See
[`fusion_manifest.json`](fusion_manifest.json) and
[`mesh_verification.json`](mesh_verification.json).

The owner's initial 19.0 mm result and its exact printed artifact are preserved
in the [physical evidence record](../../evidence/knee_fit/2026-09-15_steel_pin_provisional_shin/).

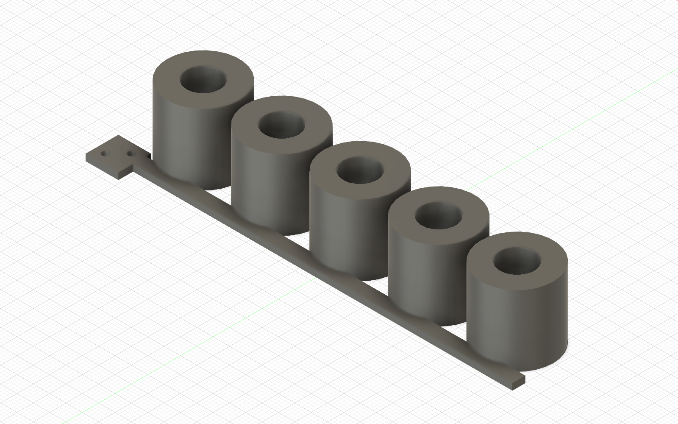
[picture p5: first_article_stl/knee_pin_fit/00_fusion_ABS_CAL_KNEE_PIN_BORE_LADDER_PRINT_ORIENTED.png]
Fusion view of the corrected print-oriented ladder


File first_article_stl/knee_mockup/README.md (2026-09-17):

# Supported knee mock-up — ABS, 2026-09-06

**Owner update, 2026-09-07:** the pin, provisional distal link and both caps
are printed; the owner reports successful provisional assembly, free supported
knee movement, easy pin removal and uncompressed fit at both spring ends.
[Photo and physical acceptance scope](../../evidence/assembly/2026-09-07_owner_mockup/).
That result remains historical evidence for the loose printed pin; the later
steel-pin result below supersedes the print disposition.

**Owner update, 2026-09-15:** the provisional distal/shin link has been
destroyed. A received metal pin was fully inserted through the installed
bearings and its nominal Ø10 printed bore, then seized in the printed bore. The
owner broke the shin pieces to recover the pin and reports that the bearings,
although snug, were not the source of the seizure. Do not reprint this
provisional link for a steel-pin trial. The owner selected Ø10.30 for the active
ABS production receiver after Ø10.25 passed the initial 19.0 mm coupon. The
[full-span ladder](../knee_pin_fit/) is now an optional diagnostic.
[Result and remaining checks](../../evidence/knee_fit/2026-09-15_steel_pin_provisional_shin/).

Do not print a replacement provisional distal link for the steel pin. The
temporary printed pin remains a loose alignment tool only. Two small caps also
let you try the ends of your **50 mm, OD18 / ID9 spring off the leg**.
The owner also confirmed the corrected proximal link and all six hub screw
seats. Keep the accepted prints; no replacement is prompted by this result.

**PHYSICAL ASSEMBLY VERIFIED — supported provisional knee hand fit only.**
Detached spring-cap fit also passes. The original CAD path verification remains
the source for the procedure below. This batch is for
two supported, detached links and gentle hand positioning. Keep motors,
cartridge, knee-stop hardware, encoder and collar off this mock-up. The pin
does not carry the leg's weight. No spring preload or powered movement.

## Print order and files

| Order | File | Quantity | Print setup |
|---|---|---:|---|
| 1 | [Temporary alignment pin](ABS_MOCKUP_Knee_Alignment_Pin_D9p7_PRINT_ORIENTED.stl) | 1 | ABS; grip on bed, shaft vertical; 0.20 mm layers, 4 walls, 100% infill; **no supports** |
| 2 | [Provisional distal link](ABS_MOCKUP_Distal_Link_L_PRINT_ORIENTED.stl) | 1 | ABS; supplied broad-face-down orientation; 0.20 mm layers, 4 walls, 5 top/bottom layers, 30% infill; **selective supports below** |
| Optional, with pin | [Detached spring-seat fit cap](ABS_Spring_Seat_Fit_Cap_D8_PRINT_ORIENTED.stl) | 2 | ABS; broad base on bed, pilot vertical; same 30% profile; **no supports** |

Use the tuned enclosed ABS profile. Import each file unchanged, with no
rotation, scaling or hole compensation. A brim is allowed if that profile
needs one. The pin is intentionally Ø9.7 in nominal Ø10 bores; it is a loose
alignment tool, not a steel-pin fit gauge or a retained axle.

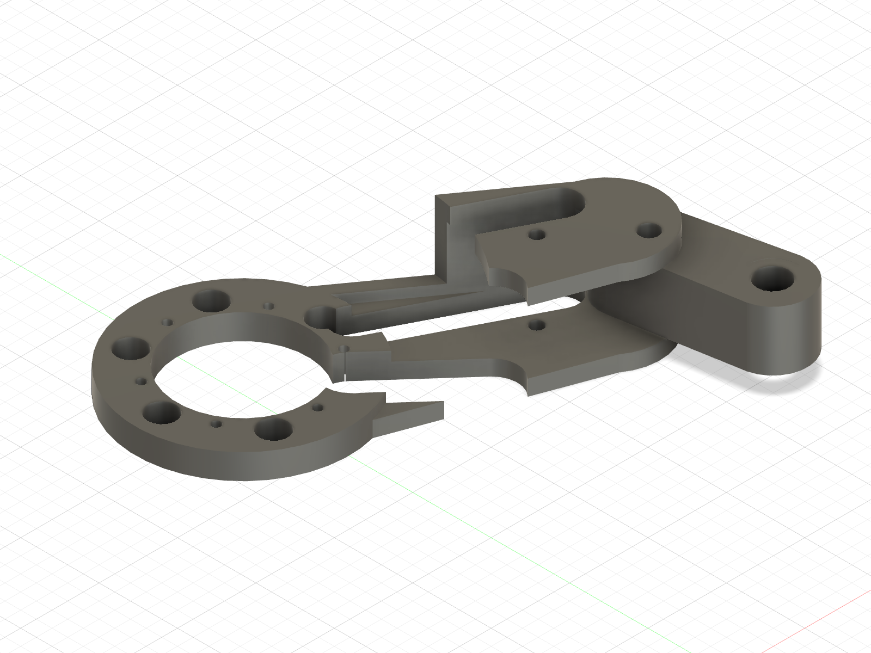
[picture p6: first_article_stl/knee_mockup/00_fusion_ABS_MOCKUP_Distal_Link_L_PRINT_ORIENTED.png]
Distal link in its supplied print orientation


## Distal supports

The wheel-mount ledge now continues down to the bed. The raised knee web and
the underside of the upper channel arm still need support. The blue volumes
below show the allowed support regions in a **different inspection view**;
use the STL's orientation for printing.

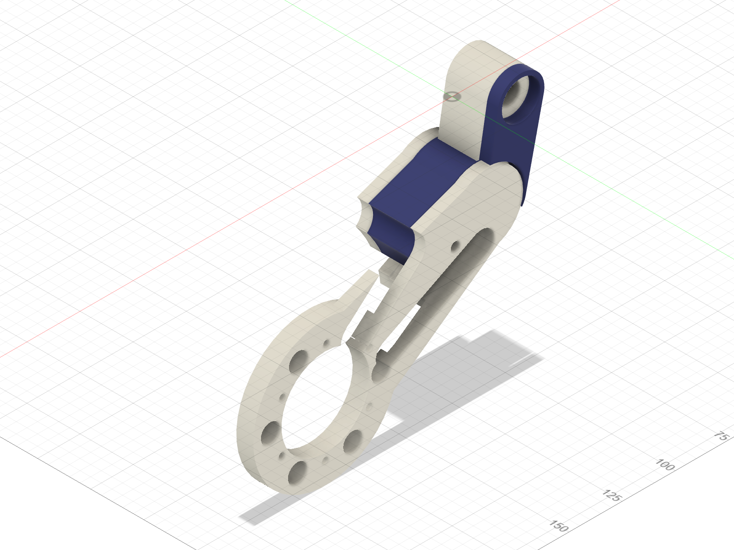
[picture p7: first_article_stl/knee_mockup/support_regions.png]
Blue support regions checked in Fusion


- Use manual/painted **normal supports** under those two regions. Allow
  supports on the lower channel floor as well as on the bed. Build-plate-only
  supports cannot reach the upper channel ceiling.
- Set support XY clearance to **0.6 mm** and top/bottom separation to
  **0.4 mm** for the 0.20 mm layer profile. Fusion checked a larger support
  envelope with 0.3 mm separation, so this leaves additional removal space.
- Keep a **Ø18 no-support region around the knee axis**, Ø8 around the small
  cartridge-pivot hole and Ø9 around the stop-pin hole. Keep every bore,
  motor mating face and bearing-contact area free of support. Do not fill
  holes with supports or let automatic supports spread beyond these regions.
- The small slot-corner ceiling and the narrow margins around blocked holes
  bridge. Inspect these layers in preview. Supports must not wrap around the
  knee boss or close the open side of the channel.
- After cooling, remove the knee-web support downward toward its bed face.
  Break away and withdraw the channel support through its **open side**,
  not through a pin hole. Fusion checked these removal paths. Do not pry
  against a bearing, bore, mating face or thin edge.

The owner has printed and assembled the first article; detailed support-removal
quality was not separately reported. Reject a print with a blocked bore, damaged wall, curled datum or
support debris that prevents the following hand fit.

## Bench assembly

1. With the existing proximal link detached and supported, pass the printed
   pin through each bearing by hand. It must slide and withdraw freely.
   Check it separately in the new distal bore after removing supports.
   Stop if it needs force; do not hammer, heat-fit or drill it to hide a failure.
2. Support **both links** on padded blocks or folded towels, with the knee
   ends at the same height. The supports carry their weight throughout the
   test. Keep the joint accessible for your fingers.
3. Hold the distal tongue between the proximal fork arms. Slide it radially
   into the open end of the fork until the three bores line up. Fusion verified
   this with both proximal bearings already installed. **No thrust spacers
   are fitted in this temporary assembly.**
4. Push the pin from the proximal link's inboard bearing, through the distal
   tongue, then through the outboard bearing. Its large grip remains outside
   the inboard face. Leave it loose; do not add a clamp, collar or magnet carrier.
5. While continuing to support both links, gently change their relative angle
   through a small range. The tongue must move without rubbing, and the pin
   must remain freely removable. Some play is intentional. Do not use this
   assembly to measure knee backlash, encoder position, stiffness or load.
6. Support the links, pull the pin out using its grip, and slide the tongue
   out of the fork. Repeat once. Record any sticking or contact before adding
   any other hardware.

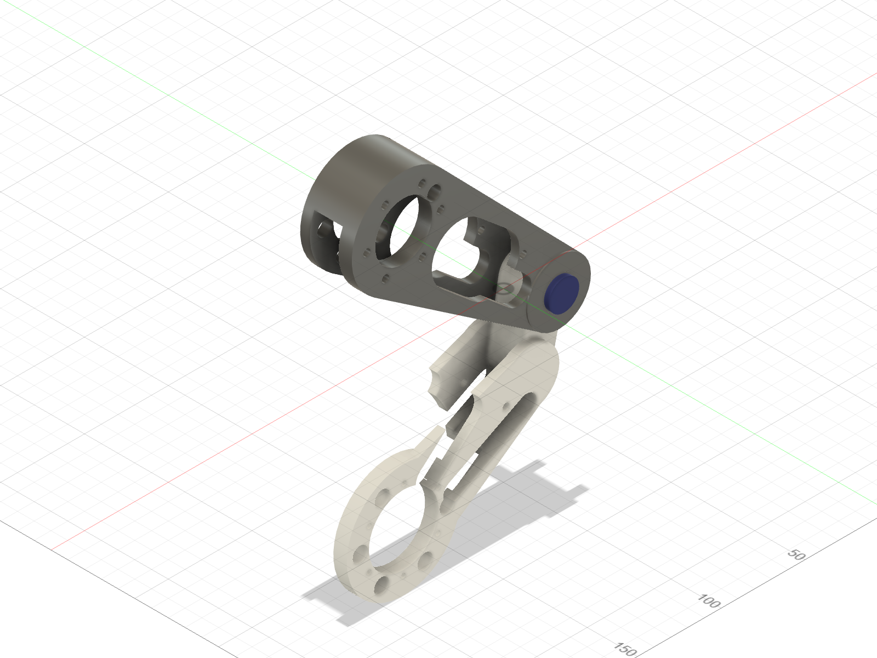
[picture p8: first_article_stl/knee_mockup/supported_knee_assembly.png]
Two-link assembly with the temporary pin shown blue


The Fusion view shows geometry, not a freestanding physical setup: keep both
links supported on the bench. No fasteners, heat-set inserts or wiring are
required for this particular rehearsal.

## Try the spring separately

Place one cap flat on the bench, pilot up. Lower one end of the uncompressed
spring over its pilot: it should seat flat without stretching the coil or
forcing the pilot in. Remove it and check the other spring end. You can place
the second cap on top under its own weight to see the end-to-end fit.
Do not squeeze the caps together or attach this stack to the links.

The cap tests an **Ø8 locating pilot** and **Ø20 seat** against the owned
spring. It is not a revised cartridge eye or a preload spacer. Actual cartridge
seats, guide/stop/bumper packaging, installed length and spring rate remain
open in the [spring record](../../evidence/springs/2026-09-05_reconciliation/).

## What carries forward

Keep the accepted shoulder hub and corrected proximal link; the owner confirmed
all six screw seats on September 7. Its [traveller](../assembly_dry_fit/)
retains the bearing inspection and assembly instructions.
This distal mock-up preserves the link outline and pivot locations but omits
the original protruding thrust lands so it can enter a fork with bearings
already fitted. Its 19 mm tongue has 0.5 mm nominal clearance to each fork arm.
It is **not a release of the final distal/steel-pin/retention stack** and may
need replacement after that stack is resolved. Do not attach a motor to it.

The three STLs, their print orientations and the native geometry were checked
through Fusion MCP. [Engineering evidence and reproducible source](../../evidence/assembly/2026-09-06_supported_knee_mockup/).

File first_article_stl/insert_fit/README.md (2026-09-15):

# ABS heat-set receiver ladders

## M3 × 5 — completed; owner selected Ø4.5

The general `GAUGE_Fit_Coupon.stl` contained only one M3 candidate. The owner
reported on 2026-09-14 that its nominal Ø4.0 hole is too small for the intended
M3 heat-set insert. [Physical result](../../evidence/inserts/2026-09-14_m3_coupon_fail/).
That gauge is not an M3 diameter ladder.

The owner printed the ladder and reported that the largest pocket, furthest
from the marker, works best. That station is nominal **Ø4.5 × 6.0 mm**.
[Physical selection and limitations](../../evidence/inserts/2026-09-14_m3_coupon_pass/).
Fusion has promoted Ø4.5 into the active ABS M3 receiver parts. The qualitative
report did not include a photograph, measured printed diameter, or separate
spin/pull result.

For reproduction, print one ABS
[`ABS_CAL_OWNED_M3x5_INSERT_POCKET_LADDER_PRINT_ORIENTED.stl`](ABS_CAL_OWNED_M3x5_INSERT_POCKET_LADDER_PRINT_ORIENTED.stl)
with the same tuned, enclosed ABS profile as the single-leg parts. Import the
file unchanged: no rotation, scaling, hole compensation or supports. Its
60 × 16 mm pocket-opening face is already on the bed. The five pockets are
vertical, blind and 6.0 mm deep, matching the Mode A stand receiver depth for
the 5.0 mm insert. Inspect the bridged pocket roofs in the slicer preview.

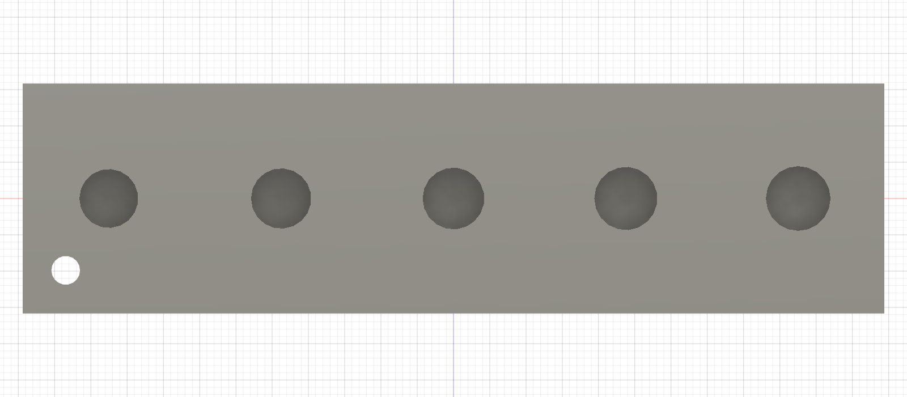
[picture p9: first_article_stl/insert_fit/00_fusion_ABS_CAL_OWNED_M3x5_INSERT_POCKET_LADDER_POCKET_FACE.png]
Fusion view of the five M3 pocket stations


The small Ø2 through marker identifies the **Ø4.1 end**. Moving away from it:

1. Ø4.1 × 6.0
2. Ø4.2 × 6.0
3. Ø4.3 × 6.0
4. Ø4.4 × 6.0
5. Ø4.5 × 6.0

Use one fresh owner-supplied Voron-style **M3 × 5** insert per attempted
station. Start at the marked Ø4.1 end and select the smallest station that:

- accepts a perpendicular heat-set without splitting, bulging or driving
  excessive plastic ahead of it;
- finishes square and flush;
- does not spin with a finger-started M3 screw after cooling; and
- resists a firm hand pull after cooling.

Stop once the first station passes. If none passes, report that result rather
than drilling, filing, scaling or changing the slicer compensation. The owner
selected station 5, Ø4.5. Repeat the coupon before transferring the value to a
different printer, filament, process profile, or the later PA-CF build.

[Fusion B-Rep and orientation manifest](owned_m3x5_insert_coupon_manifest.json) ·
[Fusion MCP verification of the exported mesh](owned_m3x5_insert_coupon_mesh_verification.json)

## M4 × 8 — completed

**Completed — owner PASS, 2026-09-04: nominal Ø5.3.** The owner confirmed
square/flush installation without splitting or bulging and secure retention
after cooling. [Physical result](../../evidence/inserts/2026-09-04_m4_coupon_pass/).
Both Fusion documents now use this ABS diameter. The procedure below remains
for reproduction and future material/profile changes.

Coupon:
[`ABS_CAL_OWNED_M4x8_INSERT_POCKET_LADDER_PRINT_ORIENTED.stl`](ABS_CAL_OWNED_M4x8_INSERT_POCKET_LADDER_PRINT_ORIENTED.stl)
was used before releasing the M4 hubs. It is for the **M4 × 8** compartment in the owner's
photographed Kadriick mixed kit. The case says 30 pieces and labels the M4
family `d1=5.5 mm`, `d2=5.0 mm`; it does not unambiguously define the required
printed-hole diameter.

The file is already on its 60 × 16 mm bed face. Do not rotate, scale, apply
slicer hole compensation, or use supports. Print it with the same tuned,
enclosed ABS profile planned for the single-leg parts.

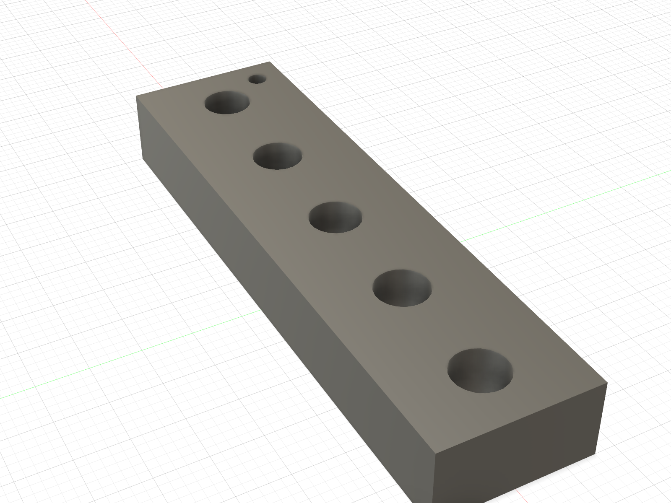
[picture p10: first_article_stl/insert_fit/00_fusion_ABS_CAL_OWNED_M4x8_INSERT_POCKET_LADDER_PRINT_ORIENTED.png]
Fusion view of the print-oriented owned-M4 coupon


The small Ø2 marker identifies the **Ø4.9 end**. Moving away from it, the five
vertical through bores are:

1. Ø4.9 × 8.0
2. Ø5.0 × 8.0
3. Ø5.1 × 8.0 — original centre candidate; Ø5.3 selected
4. Ø5.2 × 8.0
5. Ø5.3 × 8.0

Use one fresh M4 × 8 insert per attempted station. Heat it perpendicular with
a depth stop, finish flush, and let it cool completely. Select the **smallest**
station that:

- accepts the insert without splitting, bulging, or driving excessive plastic
  ahead of it;
- leaves the insert flush and square;
- does not spin under a finger-started M4 screw; and
- resists a firm hand pull after cooling.

Do not use screw torque to pull an insert into place. Record the winning
station and photograph the result. If none passes, stop and revise the ladder
rather than drilling, filing, scaling, or modifying a hub.

The selected Ø5.3 ABS diameter has been promoted through Fusion into:

- six full-depth 8.0 mm shoulder-hub receivers;
- six through receivers in the 6.0 mm wheel hub; and
- the shared source for four full-depth 8.0 mm deferred Mode-B carriage
  receivers; rebuild/verify that deferred component when Mode B returns.

The wheel's complete insert length is accommodated by the mating rim: 6.0 mm
embeds in the hub and 2.0 mm projects into a Ø6.0 × 2.2 relief. M4 × 10 was not
selected because it would require 2.0 mm more projection without improving the
joint.

The Fusion B-Rep record is
[`owned_m4x8_insert_coupon_manifest.json`](owned_m4x8_insert_coupon_manifest.json).

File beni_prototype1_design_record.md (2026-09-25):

# Beni-Like Wheeled Biped — Prototype 1 Design Record

> **REVISION 2 — 2026-08-08.** This document describes revision 1 except where
> marked. Ten defects and production gaps were closed after it was written; the
> authoritative record of what changed and why is
> **`beni_prototype1_rev2_changes.md`**, and the numbers that moved are called
> out inline below with a **[REV2]** tag.
>
> **BUILD CONSTRAINT, 2026-08-12.** This record describes Prototype 1 as
> *engineered*, with machined 7075 hubs, a ground double-D knee axle and a
> hardened steel stop arc. **None of those are built that way any more:**
> 3D printed and off-the-shelf parts only, no laser cutting or machining — see
> **[`MANUFACTURING_CONSTRAINTS.md`](MANUFACTURING_CONSTRAINTS.md)**. The
> kinematics and load cases below remain the reference; mass tables are
> historical snapshots and must be regenerated for later geometry/material changes; the *material and process* callouts are not. §7's knee-stop design is
> superseded in particular — see
> [`beni_single_leg_rig_design_record.md`](beni_single_leg_rig_design_record.md) §8.
>
> The mechanism, kinematics, spring design and load cases in §1–§7 are unchanged
> and were re-verified against the rebuilt model to 0.0000 mm. What changed was
> fastener geometry, the right leg, fillets, the tyre, the chassis builders, and
> the fact that the model now knows its own mass properties.

Companion to `beni_prototype1_fusion_guide_rewritten.md`.
Fusion project: **Biped** → `Beni_Prototype1`
Immutable references: `REF_GIM6010-8`, `REF_GIM4305-10`
Parametric build source: `beni_lib.py` (`build_all()` + `build_mirror()`
reconstructs every modelled part — **[REV2]**, this was not true in revision 1;
four parts had no builder and the side-panel builder had drifted to an older
revision, so running `build_all()` would have destroyed the chassis joint)
Export helpers: `beni_export.py` (STEP, URDF, STL)
Automated audit: `beni_lib.audit_all()` — currently **0 problems**

---

## 1. Guide verification

Every checkpoint table in the guide was recomputed independently before any
geometry was drawn, and the Fusion model was then measured against it.

### 1.1 Knee kinematics (shoulder at nominal)

| φ | vert. compression | guide | fore-aft | guide |
|---:|---:|---:|---:|---:|
| −8° | −12.04 | −12.0 | 11.63 | 11.6 |
| 0° | 0.00 | 0 | 0.00 | 0 |
| +5° | 8.31 | 8.3 | 6.37 | 6.4 |
| +10° | 17.13 | 17.1 | 12.00 | 12.0 |
| +15° | 26.42 | 26.4 | 16.83 | 16.8 |
| +20° | 36.09 | 36.1 | 20.84 | 20.8 |
| +25° | 46.08 | 46.1 | 23.99 | 24.0 |

Shoulder-to-wheel vertical at nominal = **154.269 mm** (guide: ~154.3).

### 1.2 Cartridge geometry and force

| φ | eye-to-eye | guide | moment arm | guide | spring F | guide | wheel F | guide |
|---:|---:|---:|---:|---:|---:|---:|---:|---:|
| −8° | 77.70 | 77.70 | 22.09 | 22.09 | 30.0 N | 30 | 8.25 N | 8.3 |
| 0° | 74.44 | 74.44 | 24.54 | 24.54 | 64.0 N | 64 | 17.09 N | 17.2 |
| +10° | 69.91 | 69.91 | 27.39 | 27.39 | 111.4 N | — | 29.36 N | 29.4 |
| +20° | 64.90 | 64.90 | 29.95 | 29.95 | 163.8 N | — | 43.50 N | 43.6 |
| +25° | 62.23 | 62.23 | 31.12 | 31.12 | 191.6 N | 192 | 51.44 N | 51.5 |
| +27° | 61.14 | — | 31.56 | — | 203.0 N | — | 54.80 N | — |

Extension→design stroke **15.47 mm** (guide: 15.47). Effective wheel rate
0→+25° = **0.744 N/mm** (guide band 0.71–0.80). Measured model pin-to-pin at
nominal = 74.4431 mm.

### 1.3 Cartridge internal budget

Pin-to-pin dead length **25.57 mm** (11.00 upper + 14.57 lower incl. 2.0 mm of
shims). Spring length = eye-to-eye − 25.57.

| φ | spring length | deflection | force | solid-height margin |
|---:|---:|---:|---:|---:|
| −8° | 52.13 | 2.87 | 30.0 N | 21.45 |
| 0° | 48.87 | 6.13 | 64.0 N | 18.19 |
| +25° | 36.66 | 18.34 | 191.6 N | 5.98 |
| +27° | 35.57 | 19.43 | 203.0 N | **4.89** |

Solid height = 11.8 coils × 2.6 mm = **30.68 mm**. The spring therefore cannot
coil-bind before the +27° metal hard stop, with 4.89 mm to spare.

Rate check: `k = G·d⁴/(8·D³·n) = 79300 × 2.6⁴ / (8 × 16.4³ × 9.8) = 10.48 N/mm`
against the 10.45 N/mm target.

Preload is tunable **9.1 N … 30.0 N** at φ=−8° by removing 0–4 × 0.5 mm shims.

---

## 2. Motor reference audit (measured from the supplied STEP)

### 2.1 Steadywin GIM6010-8 — shoulder
Reference datum: **housing mount face at x = 0**, motor axis = x, output toward +x.

| Feature | Value |
|---|---|
| Overall length | 44.0 mm (x = −37.0 … +7.0) |
| Housing OD | Ø80.0, x = −25.0 … −1.0 |
| Rear face | x = −26.0 |
| Driver cover | Ø57.0, x = −37.0 … −26.0, cable exit notch in cover |
| **Housing mount** | **8 × M3 on Ø74.0 PCD**, 45° spacing, ~4.0 mm thread from the front face and ~4.8 mm from the rear, Ø6.0 through-bore between |
| Front mounting land | annulus Ø47 → Ø78 at x = 0 |
| Rotating face | annulus Ø34 → Ø46 at x = +2.0 (0.5 mm gap to the Ø47 housing bore) |
| Output pilot boss | Ø34.0, x = +2.0 … +3.0 — **unusable as a register** (root fillet blends to Ø36.4) |
| **Output mount face** | **x = +3.5**, annulus Ø13 → Ø33, **6 × M3 on Ø25.0 PCD, 5 mm deep** |
| **Anti-rotation pins** | **3 × Ø4.0 on Ø20.4 PCD**, protruding to x = +7.0 (3.5 mm), tip chamfer to Ø3.6, root chamfer Ø4.6 |
| Centre | Ø12/Ø13 blind recess 0.5 mm deep — **solid, no hollow shaft** |

### 2.2 Steadywin GIM4305-10 — wheel
Reference datum: **housing mount face at x = 0**, output toward −x.

| Feature | Value |
|---|---|
| Overall length | 33.0 mm (x = −27.0 … +6.0) |
| Housing OD | Ø53.0, x = −23.0 … −0.5 (Ø54.2 over small ribs) |
| **Housing mount** | **6 × M2.5 on Ø47.5 PCD**, 60° spacing, ~3 mm deep, at x = 0, in two arc lands interrupted by four relief flats |
| Driver cover | Ø40.4, x = 0 … +6.0, retained by 2 × M2 on Ø35 PCD (heads accessible from +x) |
| Bearing gland | Ø53.0, x = −26.0 … −23.0 |
| **Output flange face** | **x = −27.0**, Ø37.0 flange OD, **3 × M3 on Ø27.0 PCD, 4 mm deep**, six kidney lightening pockets |
| Centre | Ø10 mouth → Ø12 → Ø8 blind, 3 mm deep |

---

## 3. Lateral layout (left leg, frozen)

> **The Y datum and every dimension in this table are still authoritative** — other
> documents take these rows as the reference stack, and none of the numbers have
> moved. But four rows describe *parts that no longer exist in that form*, and
> those rows are tagged **[SUPERSEDED]** inline. A superseded row is history: read
> its y-coordinates as real, and its material/process as void. Routing for each is
> in [`MANUFACTURING_CONSTRAINTS.md`](MANUFACTURING_CONSTRAINTS.md).

| y (mm) | Feature |
|---:|---|
| 5 … 16 | shoulder motor driver cover (Ø57) |
| 17 … 41 | shoulder motor housing (Ø80) |
| **42** | **housing mount face** — 8 × M3 @ Ø74 PCD |
| 42 … 47 | `Chassis_Shoulder_Plate_L` (5 mm printed plate, Ø96), including 4 owner-selected Ø4.5 through receivers for 5 mm Voron-style M3 cable-cover inserts. **Physical update 2026-09-14:** Ø4.0 failed in ABS; the ladder's unmarked-end Ø4.5 station was selected, promoted and verified through Fusion. |
| 44 | rotor face (Ø34…Ø46) |
| **45.5** | **output mount face** — 6 × M3 @ Ø25 PCD, 3 × Ø4 pins to y = 49 |
| 45.5 … 51.5 | **[SUPERSEDED]** `Shoulder_Output_Hub_L` body Ø38 (7075-T6) — **now printed**, with 3 bought Ø4 × 10 dowel pins and M4 inserts |
| 47 … 51 | cable spiral cavity, r = 20 … 32 (lip r = 32 … 33.5) |
| 51.5 … 53.5 | `Shoulder_Cable_Cover_L` (2 mm ABS ring, r = 30 … 47), 4 × Ø3.4 clearance; M3 × 10 screws enter from outboard into the plate inserts |
| 51.5 … 59.5 | hub flange Ø56, Ø6 cable port at r = 21. **[REDESIGNED 2026-09-03]** Six owner-held Kadriick M4 × 8 inserts occupy owner-passed Ø5.3 ABS through receivers across the full 8.0 mm flange. The Ø5.3 ABS result was promoted through Fusion on 2026-09-04; repeat for PA-CF. M4 × 10 link screws engage 6.2 mm and stop 1.8 mm before the motor-side insert end. The replacement hub is printed with inserts installed successfully. The printed corrected link passed all six screw seats; repeat that rehearsal after printing its required Ø4.5 M3-receiver replacement. |
| **59.5** | **leg inboard face** |
| 55.7 … 58.7 | knee axle flange Ø15 |
| 58.7 … 64.5 | proximal arm A (5 mm + 0.8 mm knee boss), 6800 bearing at 58.7 … 63.7 |
| 63.7 … 85.3 | **[SUPERSEDED]** knee steel sleeve Ø16/Ø10 (double-D bore) — **`Knee_Sleeve_L` is DELETED**; its Ø16 bore is now printed as Ø10 directly into `Distal_Link_L` |
| 64.5 … 84.5 | **spring channel, 20 mm** — cartridge centred on y = 74.5, Ø19 spring spans 65 … 84 |
| 65 … 84 | distal knee boss Ø22 (19 mm) |
| 84.5 … 90.3 | proximal arm B (5 mm + 0.8 mm knee boss), 6800 bearing at 85.3 … 90.3 |
| **89.5** | **leg outboard face** |
| 90.3 … 93.3 | **[SUPERSEDED]** `Knee_Stop_Arc_L` (3 mm steel, two-level slot) — **DELETED**; the +27° stop is a compression column of bought M5 washers, see `beni_single_leg_rig_design_record.md` §8 |
| 90.3 … 96.3 | `Knee_Magnet_Carrier_L` Ø15, magnet face at 96.3 |
| 97.3 | AS5048A die face — **1.0 mm air gap** |
| 98.3 … 99.9 | encoder PCB; bracket shelf 99.9 … 101.9 |
| 59.5 … 67.5 | distal wheel-end plate (8 mm), Ø41.5 clearance for the motor driver cover |
| **67.5** | **wheel motor mount face** — 6 × M2.5 @ Ø47.5 PCD |
| 61.5 … 67.5 | wheel motor driver cover (Ø40.4) recessed into the plate |
| 68 … 90.5 | wheel motor housing (Ø53) |
| 69 … 99 | rim + tyre, tyre OD Ø110 (**centre y = 84**) |
| **94.5** | wheel motor output flange face |
| 94.5 … 100.5 | **[SUPERSEDED]** `Wheel_Hub_L` (7075-T6, Ø56) — **now printed**, with steel washers and a re-torque schedule |
| 100.5 … 104.5 | rim web, 6 × **M4 × 8** @ Ø46 PCD into six owner-held Kadriick M4 × 8 inserts. **[REDESIGNED 2026-09-03]** Each insert occupies an owner-passed Ø5.3 ABS through receiver in the 6.0 mm hub and projects 2.0 mm into a coaxial Ø6.0 × 2.2 rim relief. The Ø5.3 ABS result was promoted through Fusion on 2026-09-04. The rim remains on a separate printability hold. Screw engagement is 6.0 mm with 2.0 mm clearance to the insert's motor-side end. |

**Track = 168 mm.** Nothing rotating crosses y = 53.5, so the chassis is free
to occupy |y| ≤ 47 without ever fouling the leg sweep.

---

## 4. Recorded assumptions and deviations from the guide

1. **Structural leg/knee width is 30 mm, not ~28 mm.** This is forced. The
   guide freezes Ru = 36, Rl = 54, 110° anchor geometry, which fixes the
   spring's minimum moment arm at 22.09 mm (φ = −8°). With the guide's Ø19
   spring that puts the cartridge's outer surface 12.59 mm from the knee axis.
   A 20 mm clear channel is therefore mandatory, and 28 mm total leaves only
   4 mm per arm — not enough for a 6800 (Ø19) bearing seat. 30 mm gives 5 mm
   arms and a 20 mm channel with 0.5 mm spring clearance per side. Everything
   else in the guide's §17 freeze list is preserved exactly.
2. **The shoulder output's Ø34 pilot boss is not used as a register** — its root
   fillet blends out to Ø36.4, leaving under 0.2 mm of usable straight land.
   The hub instead locates on the motor's **3 × Ø4.0 anti-rotation pins** in
   reamed Ø4.05 H7 holes, with the 6 × M3 as the clamp. This is a better
   interface than the 1 mm spigot would have been.
3. **No central cable route exists** — the GIM6010-8 output centre is a 0.5 mm
   blind recess, not a through bore. Guide §8 option 1 therefore fails and
   option 2 is used: a clock-spring harness cavity (r = 20…32, 4 mm tall)
   between the shoulder plate and the rotating hub flange. With Ø3.0 high-flex
   cable and ~400 mm coiled the capacity is `L(1/r_i − 1/r_o) ≈ 8.2 rad ≈ 470°`
   against the 370° requirement — 27 % margin.
4. **Wheel-motor output register is only 1 mm deep**, so `Wheel_Hub_L` centres
   on a Ø37.3 H8 × 0.8 counterbore and takes torque through 3 × M3 on Ø27 PCD
   (friction capacity ≈ 20 N·m at 3 × 3.4 kN preload).
5. **The knee stop arc is fastened with blind M3 heat-set inserts**, not
   through-bolts. A through-bolt at the required radius would put its nut
   inside the spring channel *and* inside the distal link's knee web. Load at
   the inserts is shear (≈ 5 MPa on the insert/plastic interface at the 16 N·m
   impact case), not pull-out.
6. **The spring is modelled as a swept Ø2.6 helical wire body** with the specified
   Ø19 OD and 11.8 total-coil representation. It rebuilds to the cartridge length
   at every knee pose. The earlier annular outer-envelope model established the
   conservative 0.50 mm channel clearance; coil-bind acceptance still comes from
   the specified solid height and the supplier/press check, not spline end detail.
7. **The guide rod guides the spring only for φ ≳ +13°.** The stroke (16.6 mm)
   exceeds the axial room available between the lower eye's rod bore and its
   pivot pin, so the rod withdraws at high extension. **WITHDRAWN ASSUMPTION,
   2026-09-24:** the earlier claim that this was acceptable because buckling was
   not credible below 20 % deflection is not established physical evidence.
   The active ABS cartridge uses different spring/seat dimensions, and the
   owner now reports end distortion and spring escape. Do not use this legacy
   argument to accept either build. See the [failure record](evidence/assembly/2026-09-24_spring_escape/)
   and [mechanism redesign brief](docs/design/knee_spring_redesign.md).
8. **The distal link is single-sided at the wheel.** Nothing may sit inside the
   wheel's swept annulus (r = 44…55 from the wheel axis over y = 69…104.5), so
   the fork terminates and only the 8 mm inboard plate continues to the wheel.
9. **The cartridge separates when unpinned.** The spring is captured between two
   Ø13.4 seat spigots while both pivot pins are fitted; with a pin removed the
   assembly comes apart, which is what makes the spring replaceable.

---

## 5. Load cases and margins

| Case | Load | Checked |
|---|---|---|
| Static | 17.2 N per wheel (φ = 0) | reproduces guide table |
| Knee design point | 51.5 N per wheel (φ = +25°) | reproduces guide table |
| Crash/proof screen | 275 N at one wheel (≈ 8 g) | see below |

- **Shoulder mount:** 8 × M3 into 4 mm of aluminium thread. Thread shear area
  ≈ 22.6 mm² per bolt → 4.5 kN, above the M3 12.9 proof load (3.4 kN), so the
  screw is the weak element by design.
- **Hub → output torque path:** 6 × M3 on Ø25 PCD, friction capacity
  ≈ 6 × 3.4 kN × 0.15 × 12.5 mm = **38 N·m** against the 25 N·m proof-design
  screening load, plus 3 × Ø4 dowel pins as a positive backup.
- **Root joint:** 6 × M4 on Ø44 PCD, 7 mm thread in 7075. Dominant load is the
  14 N·m roll moment from 275 N acting 51 mm outboard → ≈ 412 N peak bolt
  tension.

> **[SUPERSEDED as the governing case]** The two threaded-in-metal margins above —
> "8 × M3 into 4 mm of aluminium thread" and "6 × M4 … 7 mm thread in 7075" — are
> the **as-designed metal** numbers and are retained as such. Both joints are now
> in **printed plastic with heat-set inserts**, so the failure mode is
> insert-to-plastic pull-out, not thread shear in aluminium, and neither figure is
> the governing margin for a build. Do not recompute them here; the printed-joint
> analysis lives in `beni_rig_no_machining.md` §2.1 and
> `beni_single_leg_rig_design_record.md`.

- **Knee axle:** Ø10 in double shear at the 6800 bearings. 275 N gives 1.75 kN
  of bending at 6.4 mm → 22 MPa in the shaft. Bearing pressure on the printed
  distal boss is carried by the Ø16 steel sleeve → 1.4 MPa on PA-CF.
- **Cartridge pivot pins:** Ø4 in double shear at 203 N → 8 MPa; bearing on the
  5 mm PA-CF arms 5 MPa; on the aluminium eye 2.7 MPa.
- **Knee hard stop:** spring torque at +27° = 203 N × 31.56 mm = **6.41 N·m**;
  at the stop-pin radius of 30 mm that is 214 N, taken as 534 N with a 2.5×
  impact factor. Bearing on the printed arm B is 17.8 MPa; the contact is
  hardened Ø6 dowel against a steel slot end with a matching 3.1 mm radius, so
  the metal contact is near-conformal rather than line contact.
- **Spring fatigue:** Wahl-corrected τ at +27° = 597 MPa against ≈ 855 MPa
  static allowable for shot-peened chrome-silicon. Over the 0 → +25° duty cycle
  τ_mean = 376 MPa, τ_alt = 189 MPa against ≈ 280 MPa Goodman allowable —
  infinite life.

**FEA caveat:** none of the above is a substitute for test. For PA-CF parts,
isotropic FEA is not proof; the bench tests in §8 must precede any powered jump.

---

## 6. Landing energy

3.5 kg dropped 100 mm arrives at 1.40 m/s carrying 3.43 J.

Energy the two passive knees can absorb from φ = 0 to the +27° hard stop:
spring force rises 64 → 203 N over 19.43 − 6.13 = 13.30 mm of spring travel, so
per leg `½(64+203) × 13.30 mm = 1.78 J`, and **3.55 J for the pair** — enough
for a 100 mm free drop with essentially no margin.

> **[HISTORICAL REV2]** With the then-current model mass of **3290.1 g** rather
> than the 3.5 kg design mass, a 100 mm free drop carried **3.23 J** against the pair's
> **3.553 J** (numerically integrated, not trapezoid-approximated), so there is
> **+10 % margin** rather than ≈0 %. The 2026-09-03 receiver redesign changed
> the current mass slightly; §14 is authoritative. The corrected conclusion
> below is unchanged.

> **[CORRECTION — 2026-08-11]** Both the original and the REV2 energy comparison
> omit the m·g·Δz gravity work done during the ~50 mm of spring compression.
> Including it raises demand to **4.85 J** — a 100 mm free drop **bottoms out**.
> Passive free-drop capacity is **~49 mm** (spring-rate method; see
> `electronics/04_firmware.md` correction 3 and `fusion_brief_single_leg_rig.md`
> §4.3). The conclusion — that the shoulder must participate — is more than
> unchanged; it is stronger.

That is the quantitative reason the guide insists the shoulder participates. The
progressive PU bumper adds ≈ 0.7 J per knee at the very end of travel, and
active shoulder yielding must supply the rest. The design therefore does not
stiffen the main spring to survive the drop, and no oil damper is fitted; the
bumper pocket and the shoulder's ±185° range are the provisions kept open.

---

## 7. Knee stop design

> ### ⚠ SUPERSEDED FOR BUILDING — the whole of §7
> `Knee_Stop_Arc_L` was laser-cut 3 mm steel and is **DELETED**. The +27° hard stop
> is now a **compression column of bought M5 washers** inside the spring cartridge,
> with a printed TPU sleeve as the progressive bumper; a printed
> `RIG_Knee_Stop_Plate_L` keeps the −8° stop and a +28° backup. The authoritative
> design, the Hertzian contact-stress reasoning for every substitute considered,
> and the verification sweep are in
> [`beni_single_leg_rig_design_record.md`](beni_single_leg_rig_design_record.md) §8.
> Everything below is the as-engineered steel-arc design, kept for its angles,
> radii and load path only.

Two-level arc slot in a 3 mm steel plate (`Knee_Stop_Arc_L`) bolted to the
proximal arm-B boss, with a Ø6 hardened dowel pressed into the distal arm B at
r = 30 mm from the knee axis.

| Level | y span | Slot arc | Function |
|---|---|---|---|
| inner | 90.3 … 91.8 | 213.67° … 260.53° | **metal hard stops** at φ = +27° and φ = −8° |
| outer | 91.8 … 93.3 | 206.34° … 264.76° | houses the two replaceable PU blocks |

- Flexion bumper: 7.5 mm PU block, face at 220.67° → first contact at
  **φ = +20.0°**, crushed 3.67 mm (49 %) exactly as the pin reaches the steel
  face at +27°.
- Extension bumper: 3.0 mm PU block, face at 259.03° → first contact at
  **φ = −6.5°**, crushed 0.79 mm (26 %) at the −8° metal stop.

Both bumpers sit in open-ended bays and are replaceable without disturbing the
bearing stack. The final crash load path is dowel → steel slot end → 3 M3 in
shear → printed boss; no thin printed tab is ever the last line of defence.

> **[REV2] Two fastener defects in this joint were found and fixed:** the three M3
> screw heads overlapped and could not be fitted (now **30° spacing**, the arc
> plate grew 12° of sector, 2164 → 2463 mm³, +2.3 g each), and the blind insert
> bore was shallower than its insert so the screw bottomed out before clamping
> (now a **5.0 mm bore with M3 × 6**). Both are why `audit_fasteners()` and
> `audit_blind_holes()` exist. **Full account, with all the arithmetic:**
> [`beni_prototype1_rev2_changes.md`](beni_prototype1_rev2_changes.md) §4.

---

## 8. Recommended test sequence (before any powered jump)

1. **Print-order dry fit** — shoulder plate, hub, proximal link, distal link.
   Check the 3 × Ø4 pin holes engage the motor pins with no rock.
2. **Knee stack build** — press the bearings, fit the sleeve, insert the axle,
   torque the magnet carrier. Confirm free rotation and < 0.1 mm axial float.
3. **Static knee sweep by hand**, −8° to +27°, encoder logged. Confirm the
   encoder reads monotonically and the stops engage at the modelled angles.
4. **Spring rate verification** on a press: measure force at 6.13 mm and
   18.34 mm of deflection; expect 64 N and 192 N ±5 %. Adjust preload shims to
   land 17.2 N at the wheel with the leg at nominal.
5. **Static load test** — 17.2 N, then 51.5 N, then 275 N applied at one wheel
   through realistic worst-case directions. Inspect the knee boss, the stop
   arc's insert bosses and the wheel-end plate for permanent set.
6. **Low-energy drop tests** — 20 mm, then 50 mm, then 100 mm, unpowered, with
   the shoulder free to yield. Log knee angle. Do not proceed to a powered jump
   until the +27° stop is confirmed never to be reached at 100 mm.
7. **Cable spiral endurance** — 500 cycles of ±185° at the shoulder, then
   inspect the harness for insulation damage at both strain reliefs.

---

## 9. Items still needing outside confirmation

- **Exact GIM6010-8 variant and driver.** The guide's stale 9 N·m/25 N·m figures
  are not used. Current published variants are roughly 5 N·m rated / 11 N·m
  stall at 24 V and 4.6–5.4 N·m rated / 17.2–17.9 N·m stall at 48 V. The
  structure is proof-designed to 25 N·m regardless, but the *bus voltage,
  driver firmware and CAN/absolute-encoder configuration must be confirmed with
  the supplier* before jump tuning.
- **Spring supplier confirmation.** Ø19 OD × 2.6 mm wire × 55 mm free × ~9.8
  active coils, closed and ground ends, chrome-silicon to ASTM A877/A877M,
  shot-peened and preset. Confirm the achievable rate tolerance (±5 % assumed)
  and the actual solid height.
- **PU bumper compound.** 7.5 mm and 3.0 mm blocks at ~90 A assumed. The crush
  fraction (49 % on the flexion bumper) is at the upper end of sensible for
  polyurethane and is a bench-test tuning item.
- **PA-CF print parameters.** All mass figures assume 1.15 g/cm³ solid-equivalent.
  Wall count and infill for the links must be set so the modelled section is
  actually achieved, particularly the 5 mm arms at the knee.

---

## 10. Verification results

### 10.1 Knee sweep, shoulder at 0° (spring rebuilt at every angle)

**Clean across 11 knee angles, −8° through +27°.** The bumpers engage exactly
where they were designed to: nothing at +20° (first contact, 0 mm³), progressive
crush to +27° (12.7 mm³), and the extension pad only at −8° (1.4 mm³).

### 10.2 Shoulder sweep, −185° … +185°

**Clean across 35 shoulder poses** — 13 angles at knee φ = 0° and 11 each at
φ = −8° and φ = +27°. Whole-assembly checks (every body, both legs, chassis) at
the six corner poses (θ = −185/0/+185 × φ = −8/+27) are also clear.

**Why the sweep is clean by construction as well as by test:** all chassis
geometry lies within |y| ≤ 51 mm; the leg's inboard-most part is the output hub
at y ≥ 45.5 (Ø56 → r ≤ 28, running inside the panel's Ø48 bore); the next leg
part is the knee axle flange at y ≥ 55.7, which sits at r = 120 mm from the
shoulder axis where no chassis geometry reaches. Only the hub shares a y-band
with the chassis, and both are bodies of revolution there — so that clearance is
rotation-invariant.

### 10.3 Minimum clearances (mm)

| pair | φ = −8 | φ = 0 | φ = +27 | note |
|---|---:|---:|---:|---|
| spring ↔ proximal link | 0.50 | 0.50 | 0.50 | designed channel clearance |
| spring ↔ distal link | 0.50 | 0.50 | 0.50 | designed channel clearance |
| spring ↔ knee sleeve | 4.59 | 7.04 | 14.06 | worst case is full extension |
| proximal ↔ distal link | 0.50 | 0.50 | 0.50 | thrust-washer gap at the knee |
| upper eye ↔ proximal link | 0.50 | 0.50 | 0.50 | |
| lower eye ↔ distal link | 0.50 | 0.50 | 0.50 | |
| guide rod ↔ lower eye | 5.14 | 1.90 | 0.30 | 0.30 = the Ø5/Ø5.6 sliding fit |
| stop arc ↔ distal link | 0.80 | 0.80 | 0.80 | axial gap, plate to arm B |
| encoder die ↔ magnet | 1.00 | 1.00 | 1.00 | **the design air gap** |

> **[REV2]** The last row is the magnet-to-**package-face** clearance, not the
> die gap. The AS5048A is a TSSOP-14 ≈1.0 mm thick with the die near mid-package,
> so the true **magnet-to-die gap is ≈1.5 mm** — inside the AMS operating window
> for a Ø6 × 2.5 diametric magnet. No geometry changed; the claim was mislabelled.

| pose-independent | mm |
|---|---:|
| hub ↔ chassis side panel | 4.03 |
| hub ↔ cable cover | 2.00 |
| tyre ↔ distal link | 1.00 (radial, Ø110 tyre in the Ø112 relief) |
| knee axle flange ↔ side panel | 65.08 |
| distal link ↔ chassis frame | 113.73 |

### 10.4 Robot envelope

| | mm |
|---|---:|
| overall length (X) | 183 |
| overall width (Y) | 217 |
| overall height (Z) | 281 |
| **track** | **168** |
| ride height, shoulder axis to ground | 209.3 |

The shoulder-squat position (θ = +30°, knee held at 0°) drops the body 20.7 mm
relative to the wheel while the wheel travels 77.1 mm fore-aft — exactly the
mechanism the guide describes, with no deep static knee fold.

---

## 11. Defects found and fixed during the audits

Fourteen real defects were found across the two audit rounds — by automated
checks, not by eye — and all are fixed in the model and in `beni_lib.py`. They
ranged from cut features leaking across components, unreachable screws, nuts
landing inside the spring channel and rim bolts entering the wheel motor's
bearing gland, to a right leg that was never a complete copy, builders that
corrupted the assembly every time it was posed, a tyre with no retention, and
every body carrying the default "Steel". Three of the later seven were *hidden by
the way the earlier audits were run*: the interference sweep was executed with
screws filtered out, and the driver-access audit only ever asked whether a tool
could reach a screw, never whether two screws could coexist. **The authoritative
per-defect account, with the arithmetic and the fix for each, is
[`beni_prototype1_rev2_changes.md`](beni_prototype1_rev2_changes.md) §1–§8**;
reproducing it here would only let the two copies drift. Five new automated
checks were added so each class cannot recur — `audit_counts`,
`audit_lr_parity`, `audit_fasteners`, `audit_blind_holes`,
`audit_source_parity`.

### Automated audit results, revision 2

`audit_all()` reports **0 problems**.

- **Counts:** clean — 74 part/side entries, exactly one body each; all are single
  solid bodies, one shell and one lump each, so no enclosed voids (no trapped
  support), no disjoint lumps, no duplicate solids.
- **L/R parity:** clean — 33 part families matched by volume and face census.
- **Fastener head clearance:** clean.
- **Blind holes:** clean — every bore ≥ its insert, every screw clear of the floor.
- **Threaded receivers:** clean — shoulder hub 6 × owner-selected Ø5.3 ABS, wheel hub
  6 × owner-selected Ø5.3 ABS, wheel rim 6 × Ø6.0 protrusion reliefs, shoulder plate
  4 × Ø4.5, proximal link 5 × Ø4.5, and chassis frame 10 × Ø4.5, all at their
  specified depths/spans. The M4 ABS coupon passed on 2026-09-04 and the M3
  Ø4.5 station was selected on 2026-09-14; this does
  not close the independent link screw-loading and rim printability holds.
- **Source parity:** 37 parts in the model, 37 classified, no orphans.
- **Driver access:** 32 hex-key access envelopes (Ø3.0–3.4, 30–45 mm reach)
  modelled for every screw serviceable on the complete robot. **Zero
  driver obstructions remained in that audit.** The 2026-09-04 check uses a
  Ø3.5 driver envelope for the six M4 root positions. The later access-fixed
  link removes the two blocked head paths and restores the clipped seating land;
  its printed Ø4.0-receiver revision passed all six M4 screw seats on 2026-09-07.
- **Interference:** 72 pairs, of which **70 are screw-shank-in-tap-drill
  artifacts** and 2 are the documented M4-stud artifact. No structural clashes;
  clear at nominal and at every pose listed in §10.
- **Fillets:** 41, where there were previously none anywhere in the design.
- **Kinematics:** wheel axis matches closed form to **0.0000 mm** at
  (θ,φ) = (0,0), (0,+25), (0,−8), (−35,+12), (+185,0) after the full rebuild.

### Known modelling artifacts, not defects

- `Shoulder_Output_Hub_L` ↔ shoulder motor, 132 mm³ at any non-zero shoulder
  angle. This is exactly the volume of the motor's three Ø4 × 3.5 output pins.
  The pins rotate *with* the hub in reality; the STEP is a single body so the
  rotor cannot be separated from the stator.
- `Knee_Axle_L` ↔ `Knee_Magnet_Carrier_L`, 32.1 mm³ — the M4 stud inside the
  modelled tap drill. Screw/tapped-hole pairs generally show this.

---

## 12. Named motion positions

All ten required positions were built and verified: the wheel-axis position in
each matched the closed-form kinematics to **0.000 mm**.

| name | shoulder θ | knee φ | wheel axis (X, Z) |
|---|---:|---:|---|
| 01 Nominal stand | 0° | 0° | (0.00, −154.27) |
| 02 Shoulder squat | +30° | 0° | (−77.13, −133.60) |
| 03 Knee extension | 0° | −8° | (11.63, −166.31) |
| 04 Knee 10° compression | 0° | +10° | (−12.00, −137.13) |
| 05 Knee 20° bumper engage | 0° | +20° | (−20.84, −118.18) |
| 06 Knee 25° design point | 0° | +25° | (−23.99, −108.19) |
| 07 Knee 27° hard stop | 0° | +27° | (−25.00, −104.13) |
| 08 Jump-drive pose | −35° | +12° | (65.06, −117.38) |
| 09 Self-right sweep | +185° | 0° | (13.45, 153.68) |
| 10 Self-right sweep | −185° | 0° | (−13.45, 153.68) |

**They are not shipped as Fusion snapshots, and that is deliberate.** Rolling the
timeline back onto a snapshot makes this document resolve the two inserted motor
references to a stale version (the shoulder body reappears 26 mm out of position —
the difference between the original STEP datum and the re-datumed reference). The
leg and chassis geometry in every snapshot was correct — the wheel checked to
0.000 mm in all ten — but shipping a file whose rolled-back states contain
misplaced motors would be worse than shipping none. The proper fix is to break the
two external references (`Occurrence.breakLink()`) and re-create the snapshots;
that was not done because the mirror feature takes those occurrences as inputs and
the risk of corrupting the verified assembly outweighed the benefit.

Instead the positions are reproducible on demand:

```python
import sys; sys.path.insert(0, '/Users/neilchulani/Robots/Biped')
import beni_lib; from beni_lib import *
set_pose(theta_deg, phi_deg)      # e.g. set_pose(0.0, 25.0)
```

`set_pose()` rebuilds the helical spring body for the knee angle, then poses the
whole leg from a cached nominal state. It is the same function used for every
sweep in §10.

---

## 13. Acceptance checklist (guide §15)

> Two rows below cite deleted hardware — the "Ø16 steel sleeve" (now a Ø10 bore
> printed into `Distal_Link_L`) and the "dowel → steel slot end" load path (now a
> compression column of bought M5 washers). Both requirements are still met, by
> the substitutes in `beni_single_leg_rig_design_record.md` §4 and §8.

| requirement | status |
|---|---|
| full 360° shoulder sweep physically possible | **yes** — −185…+185 verified at φ = −8, 0, +27; clean by Y-separation as well |
| shoulder wiring survives the full sweep | **yes** — clock-spring cavity r = 20…32 × 4 mm, ~400 mm of Ø3.0 cable gives 430° against 370° needed; envelope modelled and unobstructed |
| nominal wheel axis directly below the shoulder | **yes** — (0.00, −154.269) |
| Fusion reproduces the knee kinematic checkpoints | **yes** — all seven rows to ±0.02 mm |
| Fusion reproduces the spring eye-to-eye checkpoints | **yes** — measured pin-to-pin 74.4431 at nominal, 61.141 at +27° |
| passive knee is a real revolute joint with real spring hardware | **yes** — 2 × 6800, Ø10 keyed axle, Ø16 steel sleeve, real spring/rod/seats/shims |
| spring cannot escape or coil-bind before the hard stop | **yes** — 4.89 mm above solid height at +27°; both ends captured on Ø13.4 spigots |
| knee bearings/axle physically assemblable | **yes** — sequence in the BOM document; axle inserts from inboard after the bearings and sleeve |
| spring cartridge can be replaced | **yes** — one clevis pin, no need to disturb the bearing stack, shoulder or wheel |
| bumper and hard stop have real load paths | **yes** — dowel → steel slot end → 3 × M3 shear → printed boss; PU in open-ended bays |
| knee encoder physically fits and can be wired | **yes** — AS5048A at a 1.00 mm air gap, bracket on 2 inserts, cable slot through the shelf |
| wheel motor and connectors removable | **yes** — 6 × M2.5 from inboard; the motor's own cover screws stay accessible |
| every screw has tool access | **yes** — 32 access envelopes modelled, zero obstructions |
| every nut/washer/spacer has an installation path | **HEAT-SET PATHS PASS; KNEE RETENTION HOLD** — all existing printed receivers and screw directions are explicit. The cable cover is serviced from outboard. `RIG_Knee_Collar_L` remains unreleased because its current geometry cannot retain the real pin; see `MANUFACTURING_CONSTRAINTS.md`. |
| every printed part has an explicit viable print orientation | **yes** — BOM document §1–3 |
| no inaccessible support required | **yes** — every part is single-shell, so there are no enclosed cavities |
| one-leg assembly passes all collision sweeps before duplication | **yes** — §10.1/10.2 were run on the single leg first |
| complete robot passes all shoulder/knee collision combinations | **yes** — §10.2 |
| PA-CF used for primary load paths | **yes** — links, side panels, wheel rim, chassis frame |
| structural proof cases reviewed | **yes** — §5, with the FEA caveat |
| BOM and assembly sequence complete | **yes** — separate document |

**Two items are qualified rather than clean:**

- Named positions are delivered as a reproducible API plus a verification table
  rather than as Fusion snapshots (§12).
- The mass roll-up lands at ≈ 3.30 kg against the 3.5 kg design mass, leaving
  ≈ 200 g of margin. That is real but thin, and the reduction targets are listed
  in the BOM document §8.

---

## 14. [REV2 historical snapshot] Mass properties

Revision 1 had none: every body carried the default "Steel", Fusion reported the
robot at **8174.2 g**, and there was no centre of mass or inertia tensor anywhere
in the project. Nothing downstream — balance controller, URDF, simulation —
could be built from it.

| | Historical REV2 value; predates the current access correction |
|---|---:|
| Mass (from Fusion, materials assigned) | **3308.9 g** |
| Design mass | 3500 g |
| Margin | **≈ 191 g (5.5 %)** |
| CoM X, fore-aft from the shoulder axis | **+6.47 mm** |
| CoM Y, lateral | **−0.00 mm** |
| CoM Z | −50.10 mm |
| **CoM height above the wheel axis** | **104.2 mm** |
| Ixx about CoM (roll) | 0.03231 kg·m² |
| **Iyy about CoM (pitch — governs balance)** | **0.02525 kg·m²** |
| Izz about CoM (yaw) | 0.01719 kg·m² |
| Ixz about CoM | +0.002796 kg·m² |
| Inverted-pendulum time constant √(L/g) | 0.103 s |

The helical spring and three simplified bought-assembly/presentation bodies carry
a derived density so the assembly mass remains exact: the spring at 25.3 g, the
harness spiral at 7 g, and the battery and electronics blocks at 250 g and 120 g.
They are listed in `beni_lib.MASS_OVERRIDE_G`; left and right spring materials are
recalibrated independently when their posed lengths differ.

**CoM Y = −0.00 mm is now a standing symmetry check.** Any part missing from one
leg shows up in it immediately — it is how the missing right-hand spring
(§11 [REV2] item 11) was caught.

**The +6.47 mm fore-aft offset is inherent, not a defect.** The two links and the
knee hardware sit around X = +45…+92 while both wheels and both shoulder motors
sit at X = 0. Moving the battery aft (centre X = −0.5 → −30.5) and placing the
electronics block at X = −52 took it from +11.97 mm to about +6.47 mm; nulling it
entirely would need ≈89 mm of travel on the whole 450 g chassis group, which does
not exist in a 110 mm frame. In service it is a **0.21 N·m standing bias**
(0.11 N·m per wheel) and it means the equilibrium stance sits a few degrees off
the nominal pose. That is a controller trim term.

Per-link masses and full inertia tensors for all six moving links:
`sim/beni.urdf` and `sim/beni_inertia.json`. The exporter asserts mass closure —
every gram in the assembly must land in exactly one link.

## 15. [REV2] Why there are still no Fusion joints

Live Fusion joints were deliberately not added — they constrain occurrence
transforms and so cannot coexist with the scripted posing (`beni_lib.set_pose()`)
that every sweep and clearance table in §10 runs on. Full reasoning and what was
provided instead (URDF limits, `web/index.html`, Fusion user parameters):
[`beni_prototype1_rev2_changes.md`](beni_prototype1_rev2_changes.md) §12.

## 2026-09-05 assembly-access correction

The [current access audit](evidence/assembly/2026-09-05_access_fix/) records the
owner-triggered proximal-link wall and incomplete-seat corrections, continuous
screw/head/driver checks and revised ABS export. The six screw seats, bolt
patterns and assembly Y datums are retained; the large lightening opening is
shorter to preserve the complete seating lands. Shoulder housing screws in
CAD/source now match the physically accepted M3 × 8. Regenerate mass/inertia
exports before using the historical REV2 simulation values for a new build.

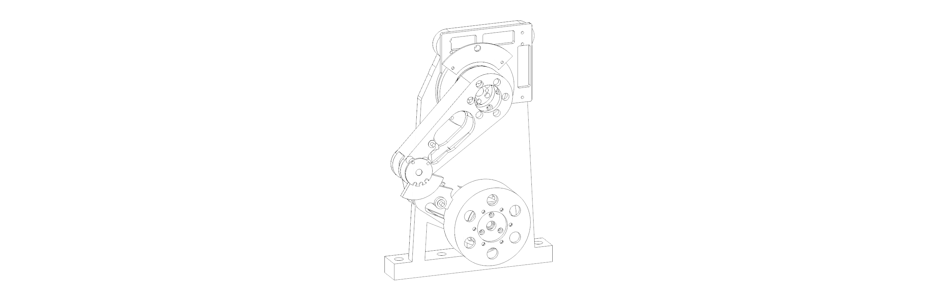
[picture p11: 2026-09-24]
docs/assembly/manual/views/00_overview.png

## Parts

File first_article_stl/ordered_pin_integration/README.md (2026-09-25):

# Ordered-pin mechanical integration — print and assembly traveller

**Spring-installed motion HOLD — September 24:** the owner reports spring
bowing and sideways escape during compression after assembly. Keep motors
unplugged and do not repeat spring compression pending diagnosis. Spring-free,
supported inspection may continue. [Physical failure record](../../evidence/assembly/2026-09-24_spring_escape/).
The spring-installation and hand-test steps below are held.

Status: `FUSION VERIFIED / PRINT RELEASE / FINAL-PART HAND FIT PENDING`

Start with the [21-step illustrated assembly manual](../../docs/assembly/ordered_pin_picture_guide.md)
or its [printable PDF](../../output/pdf/beni_single_leg_assembly_manual.pdf)
at the bench; the detailed checklist remains below.

**September 23 correction: reprint the shoulder hub and both links from
PINREV2. Keep the existing closed-skin stop plate.** The September 22 distal
STL was mislabeled D10p30 but contained Ø16; its replacement restores the
Ø10.30 × 20.0 receiver. Root-dowel sockets and clevis-link passages now use
owner-requested **Ø4.30**, +0.05 mm beyond the Ø4.25 ladder selection, for easier
hand removal. This is a new fit candidate; final-part hand fit remains open.
Motor-pin passages, knee bore, cartridge eyes and captive stop clearances are
otherwise unchanged. See the [all-15-part audit](../../evidence/assembly/2026-09-23_mechanical_reprint_audit/)
for evidence and the keep/reprint decision for every part.

The three PINREV2 files below replace the corresponding September 22 prints.
The fourth row is retained hardware, not another required reprint.

| Part | Qty | Import orientation and supports |
|---|---:|---|
| [`ABS_PINREV2_Shoulder_Output_Hub_D4p15_ROOT_D4p30_PRINT_ORIENTED.stl`](ABS_PINREV2_Shoulder_Output_Hub_D4p15_ROOT_D4p30_PRINT_ORIENTED.stl) | 1 | Import unchanged with the Ø56 outboard flange on the bed. No supports. The three root-socket ceilings are controlled bridges. |
| [`ABS_PINREV2_Proximal_Link_D19p15_ROOT_D4p30_CLEVIS_D4p30_PRINT_ORIENTED.stl`](ABS_PINREV2_Proximal_Link_D19p15_ROOT_D4p30_CLEVIS_D4p30_PRINT_ORIENTED.stl) | 1 | Import unchanged with the broad outboard face on the bed. No support in bearing seats, root sockets, clevis bore, or open channel. |
| [`ABS_PINREV2_Distal_Link_D10p30_D6x10_CLEVIS_D4p30_PRINT_ORIENTED.stl`](ABS_PINREV2_Distal_Link_D10p30_D6x10_CLEVIS_D4p30_PRINT_ORIENTED.stl) | 1 | Import unchanged with the broad inboard face on the bed. Use support only under the knee-receiver land, raised web, wheel-end underside, and open-channel ceiling. Block support from every fit bore. |
| [`ABS_PINREV_Knee_Stop_Plate_15deg_D6x10_CAPTIVE_PRINT_ORIENTED.stl`](ABS_PINREV_Knee_Stop_Plate_15deg_D6x10_CAPTIVE_PRINT_ORIENTED.stl) | 1 | Import unchanged with the closed 0.8 mm skin on the bed and the pin channel opening upward. No supports. |

Use the tuned enclosed-ABS profile: **0.20 mm layers, 4 walls, 5 top and 5
bottom layers, 30% infill**. Do not rotate, scale, compensate holes, drill,
sand, file, or heat-fit a failed article.

The PINREV2 hub and links supersede their prior versions. Keep the ordered-pin
closed-skin stop plate; the older September 17 stop plate remains superseded. Reuse the unchanged two
50 mm cartridge eyes, guide bar, D10 knee-pin spacer, encoder-bracket keeper,
and no-tyre wheel shell from the
[`mechanical_spring_test`](../mechanical_spring_test/) batch.
Keep superseded hub/link prints and the old September 17 stop plate out of
the active assembly. The superseded September 22 hub, link and mislabeled Ø16
distal files were removed from this folder on September 23; they remain in
git history at `56b2507`. On September 23 the owner confirmed that the printed
stand and shoulder plate were made after the Ø4.5 M3-receiver promotion, so
both are current. [Owner report](../../evidence/assembly/2026-09-23_owner_stand_plate_and_washers/).
The already reported printed cable cover, front cable post, and wheel hub are
reusable after their pending fits and insert checks.

## Hardware consumed from the order

- 3 × Ø4 × 10 mm cylindrical dowels at the shoulder hub/root interface
- 2 × M4 × 40 mm single-hole clevis pins and their supplied cotters
- 1 × Ø6 × 10 mm cylindrical dowel at the knee stop

Also use 2 × ISO 7089 M4 steel washers, 4.3 × 9 × 0.8 mm, and 3 × M3 × 10
socket-head screws from the fastener inventory. The washers are the specified
bearing surface for the cotters; do not replace them with printed spacers.

**Washer deviation, September 23:** the owner has no M4 washers and will try
this unpowered article without them. Each clevis pin then floats up to 1.2 mm
instead of 0.4 mm and its cotter bears on the ABS land. This is accepted only
for the clamped, unplugged, hand-contained test: inspect both cotter faces
after step 11 and fit washers before repeated cycling or powered use.
[Arithmetic and limits](../../evidence/assembly/2026-09-23_owner_stand_plate_and_washers/#iso-7089-m4-washers).

No dimensional measurement is required. The seller dimensions are already in
the CAD, and the owner requested Ø4.30 after selecting Ø4.25 with the actual pins.
Check that the pieces are undamaged and perform the final-part hand-fit steps
below. A pin that needs drilling, filing, hammering, or screw pull-down is a
failed interface, not a request to rework the hardware.

## Kit check

Collect everything before step 1. Counts come from the steps below; skip any
insert already installed in an accepted part.

| Group | Items |
|---|---|
| Printed, reprint | new PINREV2 shoulder hub (D), proximal link (E), distal link (G) |
| Printed, keep | stand (A), shoulder plate (B), cable cover, front cable post, stop plate (K), upper and lower cartridge eyes (L, N), guide bar (M), knee-pin spacer (Q), keeper bracket (P), no-tyre shell (R), wheel hub (J) |
| Actuators and bearings | GIM6010-8 (C) and GIM4305-10 (H), both unplugged; 2 × 6800-2RS (F) |
| Pins and spring | Ø10 × 35 steel knee pin; 3 × Ø4 × 10 dowels; 2 × M4 × 40 clevis pins with supplied cotters; 1 × Ø6 × 10 dowel; owned OD18 / ID9 / 50 mm spring; 2 × ISO 7089 M4 washers (**not in hand**, see deviation above) |
| Heat-set inserts | 12 × M4 × 8: 6 in hub D, 6 in wheel hub J. 14 × 5 mm M3: 5 in proximal E, 4 in plate B, 5 in stand A |
| Socket-head screws | M2.5 × 12: 6 (wheel motor). M3 × 8: 11 (8 shoulder housing, 3 wheel hub). M3 × 10: 16 (5 plate-to-stand, 2 lower cover, 6 shoulder hub, 3 stop plate). M3 × 12: 2 (post and upper cover). M3 × 16: 2 (keeper bracket). M4 × 8: 6 (no-tyre shell). M4 × 10: 6 (proximal root) |
| Bench | clamps for the stand, depth-controlled insert tip, hex keys, pliers for the cotters |

## Ordered assembly

Keep both motor power and communication cables unplugged. Support the links,
knee and wheel during detached fit work. Clamp or bolt the current Mode A stand
to the bench before attaching the leg; keep the wheel clear of the bench and
floor. The two ISO 7089 M4 washers for the clevis cotters are not in hand; the
steps below note where they go if fitted later.

1. Sort and inspect the prints. Use the three PINREV2 parts, retained closed-skin stop plate and the six
   retained September 17 pieces, not the previous hub, links or stop plate.
   Reject cracks, lifted mating faces, blocked bores, damaged bearing lips, or
   a damaged closed skin on the stop plate. The stand and shoulder plate in
   hand are the owner-confirmed Ø4.5 M3-receiver versions. Keep the spring
   off the leg for the first fit and stop checks.
2. Rehearse detached interfaces before inserts or a loaded stack. Each 6800
   bearing must fit squarely in the **new** proximal link with thumb pressure
   on its outer race and no perceptible rock; transfer bearings from the older
   link only if they come out undamaged. Run the steel D10 pin through each
   bearing separately. With both bearings installed, offer the new distal link
   into the fork and insert the steel pin from inboard by firm thumb pressure.
   It must fully seat, withdraw by hand, and have no free spin or radial rock
   in the Ø10.30 × 20.0 printed receiver or unacceptable axial play. Check
   that each M4 × 10 root screw passes through the new proximal access path and
   sits flat. Separately check the guide, spring pilots, cartridge eyes, both
   M4 × 40 pins, and spacer-to-bracket locator using the
   [September 17 detached-fit steps](../mechanical_spring_test/README.md#detached-fit-checks).
   Stop at any failed fit; do not drill, file, hammer or use screws to draw
   parts together.
3. Install inserts in detached, accepted prints per the
   [receiver map](../../docs/assembly/heatset_receiver_map.md): six owned
   M4 × 8 inserts from the **new hub's outboard/link face**, five M3 inserts in
   the **new proximal link** (three stop, two bracket), and the released stand,
   shoulder plate and wheel-hub inserts if they have not already been fitted.
   Keep the three root-dowel sockets clear of heat and plastic. Let each
   receiver cool and reject a proud, tilted or loose insert. The stop plate,
   distal link, cartridge eyes and cable cover receive no inserts.
4. With the hub detached and its flange supported flat, start three Ø4 × 10
   dowels straight into its Ø4.30 blind sockets by hand. Seat each 5.0 mm deep. Stop for whitening,
   splitting or a cocked pin. Offer the proximal root over their exposed halves
   as a trial: its Ø4.30 × 5.2 sockets must let the faces meet by hand. Confirm hand withdrawal and no objectionable play with the root assembled.
   Support the dowels while mating the root; the screws capture them. Remove
   the proximal link for the shoulder and cable-cover steps.
5. Assemble the shoulder in the established order: fit the current shoulder
   plate over the **bare output rotor** of the unplugged GIM6010 and fasten the
   stationary housing with **8 × M3 × 8**; attach the plate to the clamped
   stand with **5 × M3 × 10**. Route the real cable and fit the already printed
   cable cover/front post before the link if those are included in this
   article. The upper post/cover screws are **M3 × 12**, the lower two are
   **M3 × 10**. Rehearse cable and tie clearance without energizing either
   motor. Align the hub on the motor's three factory pins, seat it against the
   metal output face by hand, and fit **6 × M3 × 10** output-hub screws.
   Follow the [shoulder picture guide](../../docs/assembly/shoulder_to_proximal_link.md)
   for the plate/rotor direction and service order.
6. Support the knee end and bring the new proximal root straight onto the
   three protruding dowels. Confirm full face contact **before** starting its
   **6 × M4 × 10** screws; then finger-start all six and check every head sits
   flat. The screws clamp the joint and make the dowels axially captive. Remove
   and refit once if necessary to prove the service path.
7. Prepare the wheel end while the distal link is detached: fit the unplugged
   GIM4305 with **6 × M2.5 × 12** from the inboard side, and fit the accepted
   wheel hub to its output with **3 × M3 × 8**. The hub's six M4 inserts are
   installed from its motor face before this joint. Keep the no-tyre shell off
   until the knee, stop and cartridge have passed their fits; keep the TPU tyre
   off this test article.
8. With both bearings in the new proximal fork, insert the detached distal
   link and the D10 steel pin from the inboard side. Confirm hand withdrawal
   again. Put one Ø6 × 10 dowel in the distal link's Ø6.2 × 4.5 blind stop
   socket, then fasten the **new closed-skin stop plate to the proximal link's
   three M3 inserts** with **3 × M3 × 10**. The plate captures the dowel with
   0.3 mm axial clearance; no glue or press fit is used. Before adding the
   spring, hand-pose the supported knee and confirm positive stops at -8° and
   +15° without binding or bypass.
9. With the knee at -8°, fit the upper cartridge eye radially, then pass an
   M4 × 40 clevis pin **inboard to outboard** through the actual link/eye stack.
   Put one ISO 7089 M4 washer against the printed outboard face (omitted under
   the September 23 washer deviation) and fit the supplied cotter, oriented
   radially away from the knee. Insert the guide
   through the **round center of the upper Ø8 spring pilot**, slide the free
   50 mm spring over it, and slide the lower eye onto the exposed guide and
   into the distal clevis. Its pin must pass with fingertip pressure. Add the
   second washer (if in hand) and cotter in the same orientation. Seat cotters
   fully without reshaping them and add no printed spacers. If the lower eye
   needs more than slight hand compression, stop rather than pulling it in
   with a pin, screw or clamp.
10. Put the D10 outboard spacer's locator in the printed bracket's center hole
    and attach the bracket to the proximal link's two M3 inserts with
    **2 × M3 × 16**. The spacer limits outboard knee-pin travel; hand control
    still prevents inboard escape during this test. Fit the no-tyre wheel shell
    to the accepted wheel hub with **6 × M4 × 8**; keep it suspended. Remove
    the bracket before servicing the stop screws, and remove the stop and
    cartridge hardware before withdrawing the knee pin.
11. Only after those detached and spring-free checks pass, perform the
    [September 17 unpowered hand test](../mechanical_spring_test/README.md#hand-test).
    With one hand containing the distal side, move slowly through -8°, 0°,
    +5°, +10° and +15°. Stop for binding, whitening or cracking, coil contact,
    guide escape, pin migration, a loose cotter or stop bypass. Record the
    settle/return tendency; it does not establish spring rate or authorize
    powered motion. Without washers, finish by inspecting both cotter contact
    faces for indentation or whitening.

The ordered hardware remains `FINAL-PART HAND FIT PENDING` until these binary
checks pass. This does not require calipers and does not authorize powered
motion, ground contact, added mass, or structural testing.

## Verification record

The September 23 correction verifies measured Ø4.30 root/clevis-link holes,
the restored Ø10.30 × 20.0 knee receiver, complete proximal screw seats,
40 mm clevis insertion paths, washer/cotter space and captive Ø6 stop stack.
The 24-pose -8°…+15° sweep, link/pin service paths and selective-support removal
checks pass. Each released STL is a closed manifold and matches the reviewed
Fusion geometry and bed orientation. See the [full audit and regression
checks](../../evidence/assembly/2026-09-23_mechanical_reprint_audit/) and
[`fusion_manifest.json`](fusion_manifest.json). New Ø4.30 physical fits remain
unverified until the replacement prints pass the hand checks.

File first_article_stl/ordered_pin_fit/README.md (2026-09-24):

# Ordered-pin ABS fit ladders

Status: `OWNER SELECTED / CAD PROMOTED`

These two inexpensive calibration parts used the real ordered hardware as
go/no-go gauges, so **no measurement or calipers were required**. Their
September 22 results are now promoted into Fusion v29 and the refreshed
[ordered-pin production files](../ordered_pin_integration/). **[SUPERSEDED
2026-09-23: the owner then requested Ø4.30 for both interfaces, one step
beyond these selections, for easier removal; PINREV2 in Fusion v30 carries it.
The clevis ladder's fourth station from the two-marker end is Ø4.30 and can
preview that fit; the root ladder stops at Ø4.25.]**

## Selected results

- Root dowel: **Ø4.25**, the largest station farthest from the two-marker end.
  The owner reported it was relatively tight, pressed in with a thumb, and
  pulled out with pliers. This is the retained hub side; inspect each final hub
  socket for whitening or cracking during installation.
- M4 × 40 clevis pin: **Ø4.25**, the middle station. The owner reported that it
  worked well. This is the removable proximal/distal link-passage value; still
  confirm hand insertion and withdrawal through the completed link/eye stacks.

| File | What it reproduces | Size |
|---|---|---:|
| [`ABS_CAL_D4x10_ROOT_BLIND_SOCKET_LADDER_PRINT_ORIENTED.stl`](ABS_CAL_D4x10_ROOT_BLIND_SOCKET_LADDER_PRINT_ORIENTED.stl) | Five 5.0 mm-deep blind sockets with the final hub's 3.0 mm closed floor | 130 × 20 × 8 mm |
| [`ABS_CAL_M4x40_CLEVIS_LINK_LAND_LADDER_PRINT_ORIENTED.stl`](ABS_CAL_M4x40_CLEVIS_LINK_LAND_LADDER_PRINT_ORIENTED.stl) | Five Ø14 bosses with the longest actual 9.0 mm clevis-link passage | 130 × 15 × 9 mm |

Import both STLs unchanged. Use the same tuned enclosed-ABS profile as the
final parts: **0.20 mm layers, 4 walls, 5 top and 5 bottom layers, 30% infill**.
Do not rotate, scale, compensate holes, drill, sand, file, or ream. Neither
ladder needs supports. A brim is permitted on the clevis ladder.

The two Ø2 marker holes identify the small-diameter end. The test station
closest to those markers is the first value below; each station farther away
increases by 0.05 mm.

## Ø4 × 10 root-dowel blind sockets

Stations from the two-marker end: **Ø4.05, Ø4.10, Ø4.15, Ø4.20, Ø4.25 mm**.

1. Use actual Ø4 × 10 cylindrical dowels from the order, not an M4 clevis pin.
2. Start at the farthest station, Ø4.25. If it is loose, move one station
   toward the two markers, using a fresh dowel when necessary.
3. Select the smallest station where the dowel starts straight by hand, seats
   the full 5 mm with gentle smooth-jaw vise or arbor-press pressure, remains
   retained when the coupon is inverted, and causes no whitening, bulging, or
   cracking. Never hammer the pin.
4. It is acceptable to leave a retained test dowel in the selected station.
   The order contains enough dowels; do not damage the coupon trying to recover
   one.

This selects only the hub's locating/retaining side. The proximal link's
Ø4.25 × 5.2 mm sockets remain intentionally looser so the faces can mate by
hand before the six M4 screws clamp the joint.

## M4 × 40 clevis-link passages

Stations from the two-marker end: **Ø4.15, Ø4.20, Ø4.25, Ø4.30, Ø4.35 mm**.

1. Use one actual M4 × 40 single-hole clevis pin from the order.
2. Start at the farthest station, Ø4.35, and move one station at a time toward
   the two markers.
3. Select the smallest station the pin crosses completely with fingertip
   pressure and withdraws from by hand, without free radial rock. Do not use a
   hammer, clamp, abrasive, or drill.

The 9 mm passage is deliberate. Fusion inspection found the final link lands
are 5.0, 5.8, 8.2, and 9.0 mm long. The cartridge eyes between them already
have Ø4.4 × 19 mm passages. A solid 34 mm coupon would not reproduce the real
interrupted stack and could incorrectly select an oversized, sloppy bore.

## Recorded result

The recorded selections are `root dowel Ø4.25; clevis Ø4.25`. No pin dimensions
were requested or used. The hub, proximal link, and distal link were rebuilt in
Fusion and their bed-ready STLs were re-exported after the selection.

There is no Ø6 × 10 ladder. The stop pin is deliberately captured in a Ø6.2
clearance socket by the stop plate's closed skin; its socket neither locates
nor retains the joint, so a tighter empirical fit would add risk without
improving the mechanism.

Fusion B-Rep and mesh evidence, exact station geometry, orientations, and file
hashes are in [`fusion_manifest.json`](fusion_manifest.json). The owner report
and Fusion release record are in the
[release evidence](../../evidence/assembly/2026-09-22_ordered_pin_fit_ladders/).

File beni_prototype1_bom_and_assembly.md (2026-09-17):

# Beni Prototype 1 — Bill of Materials and Assembly Sequence

> ### ⚠ §4, §5 and the §8 roll-up are superseded for building
> **3D printed and off-the-shelf parts only, no laser cutting or machining** —
> [`MANUFACTURING_CONSTRAINTS.md`](MANUFACTURING_CONSTRAINTS.md), which carries the
> routing table for all ten machined families. §1–§3, §6, §7 and §9–§10 stand.
> See the banners on §4 and §8 before quoting any mass. Four assembly steps in §9
> reference deleted parts and are annotated inline.

**Revision 2 — 2026-08-08.** Masses in this revision are read straight out of
the Fusion model with real physical materials assigned, not computed by hand.
See `beni_prototype1_rev2_changes.md` for what changed and why.

**DFM refresh — 2026-09-01.** Fusion re-measured the §1 printed families after
the proximal face-flat redesign and the current scripted distal-link reroute.
The displayed §1 values and subtotal are the exact Fusion results from that
source build; the PA-CF density is unchanged.

Quantities are **per robot** (two legs) unless noted. Left-hand parts are named
`*_L`; the right leg is the mirror image about Y = 0 and uses the same part
numbers with `_R`.

Masses are computed from the modelled solid volume × the density in the table.
Printed parts assume solid-equivalent density; see the note at the end.

---

## 1. Printed parts — PA-CF (carbon-filled nylon, ρ = 1.15 g/cm³)

| Part | Vol cm³ | Mass g | Qty | Total g | Print orientation |
|---|---:|---:|---:|---:|---|
| `Chassis_Shoulder_Plate_L/R` (side panel incl. motor interface) | 40.2337 | 46.2687 | 2 | 92.5375 | flat, panel face on the bed; spiral lip prints up, no support |
| `Proximal_Link_L/R` | 66.7915 | 76.8102 | 2 | 153.6204 | outboard arm/bearing face flat, bearing axes normal to the bed; bed-ready export only, supports off, 20.0 mm channel bridge |
| `Distal_Link_L/R` | 46.1144 | 53.0315 | 2 | 106.0631 | **PA-CF HOLD** — repeat the fit calibration for PA-CF. For the active ABS single-leg article, Fusion v26 uses a serviceable Ø10.30 × 20.0 mm receiver and the separate bed-ready fit article is released; physical fit, retention and encoder coupling remain open. |
| `Wheel_Rim_L/R` | 67.4501 | 77.5676 | 2 | 155.1352 | **PRINTABILITY HOLD:** web-down orientation has unsupported internal and retaining-flange ledges; do not print until resolved. Carries the tyre bead groove, inboard retaining flange, owned-M4×8 insert-tip reliefs, and a Ø38 web opening that preserves a 1 mm ligament to those reliefs |
| `Chassis_Frame` (centre cage, not mirrored) | 61.1724 | 70.3483 | 1 | 70.3483 | flanges vertical, open box, no support |
| **Subtotal** | | | | **577.7044** | |

## 2. Printed parts — ABS (ρ = 1.04 g/cm³)

| Part | Vol cm³ | Mass g | Qty | Total g | Print orientation |
|---|---:|---:|---:|---:|---|
| `Shoulder_Cable_Cover_L/R` | 15.44 | 16.1 | 2 | 32.1 | flange face down, wall prints up |
| `Knee_Encoder_Bracket_L/R` | 2.61 | 2.7 | 2 | 5.4 | shelf face down, posts print up |
| `Electronics_Tray` (centre, not mirrored) | 8.51 | 8.9 | 1 | 8.9 | flat |
| **Subtotal** | | | | **46.4** | |

## 3. Printed parts — TPU 95A (ρ = 1.20 g/cm³)

| Part | Vol cm³ | Mass g | Qty | Total g |
|---|---:|---:|---:|---:|
| `Wheel_Tyre_L/R` (Ø110 crowned × 30, **free ID Ø94**) | 66.71 | 80.1 | 2 | 160.1 |

The tyre is **modelled at ID Ø96 in its installed, stretched state** so it does
not read as a permanent interference in every future audit. **Order it at free
ID Ø94** — 2 mm of stretch onto the Ø96 rim seat. Revision 2 also added:

- an **internal bead rib** at r = 46.5 → 48 over y = 82.5…85.5, mating a groove
  cut in the rim drum, which locks the tyre axially and in torsion without
  relying on friction. As previously modelled the tyre ID exactly equalled the
  rim OD, so there was no press fit at all and it would have spun under braking;
- an **inboard flange** on the rim at r = 48 → 52 over y = 68…69 for the tyre to
  butt against, so it cannot walk off inboard (there was nothing there before);
- a **crowned tread**, R150.4, dropping 0.75 mm from Ø110 at the centre plane to
  Ø108.5 at each edge — a contact patch instead of 30 mm of line contact, which
  is what gives the machine any camber tolerance at all.

## 4. Formerly-machined families — historical masses, not a shopping list
### Was 7075-T6 aluminium (ρ = 2.81 g/cm³)

> **Do not order from §4 or §5.** These are the ten machined families **as they
> were designed**, retained for their masses and key features. All ten are
> rerouted to printed or bought parts — the part-by-part routing table (was /
> now / where it is written up) is in
> [`MANUFACTURING_CONSTRAINTS.md`](MANUFACTURING_CONSTRAINTS.md). `Knee_Sleeve_L`
> and `Knee_Stop_Arc_L` are **deleted outright**. The 414.7 g of §4 + §5 parts
> below does not exist in this form in any build.

| Part | Vol cm³ | Mass g | Qty | Total g | Key features |
|---|---:|---:|---:|---:|---|
| `Shoulder_Output_Hub_L/R` | 20.83 | 58.5 | 2 | 117.0 | 3 × Ø4.05 H7 dowel holes @ Ø20.4 PCD; 6 × Ø3.4 c'bore Ø6.2 @ Ø25 PCD; 6 × M4 @ Ø44 PCD × 7 deep; Ø6 cable port at r = 21 |
| `Wheel_Hub_L/R` | 12.69 | 35.7 | 2 | 71.4 | Ø37.3 H8 × 0.8 register; 3 × Ø3.4 c'bore Ø6.5 @ Ø27 PCD; 6 × M4 @ Ø46 PCD × 6 deep |
| `Cart_Upper_Eye_L/R` | 5.27 | 14.8 | 2 | 29.6 | Ø4.15 pivot bore; Ø5.0 H7 rod press bore; Ø13.4 × 4 spring spigot |
| `Cart_Lower_Eye_L/R` | 6.00 | 16.9 | 2 | 33.8 | Ø4.15 pivot bore; Ø5.6 rod bore 8.5 deep; Ø13.4 × 6 spring spigot |
| **Subtotal** | | | | **251.8** | |

## 5. Formerly-machined families, continued — was steel (ρ = 7.85 g/cm³)

*Historical masses, not a shopping list — see the §4 banner.*

| Part | Vol cm³ | Mass g | Qty | Total g | Notes |
|---|---:|---:|---:|---:|---|
| `Knee_Axle_L/R` | 2.82 | 22.1 | 2 | 44.2 | Ø10 h6 × 31.6 journal, Ø15 × 3 flange, **8.40 across flats** over the sleeve, M4 × 8 tapped outboard end |
| `Knee_Sleeve_L/R` | 2.75 | 21.6 | 2 | 43.2 | Ø16 OD × 21.6, **double-D bore 8.6 across flats** (axle 8.40) |
| `Knee_Magnet_Carrier_L/R` | 1.09 | 8.6 | 2 | 17.2 | Ø15 × 6 with M4 × 8 male stud and Ø6.1 × 2.5 magnet pocket |
| `Knee_Stop_Arc_L/R` | 2.46 | 19.4 | 2 | 38.7 | 3 mm plate, hardened; two-level arc slot; bolt circle now 30° spaced; see the design record §7 |
| `Cart_Guide_Rod_L/R` | 0.98 | 7.7 | 2 | 15.4 | Ø5 × 50, one end press fit |
| `Cart_Preload_Shim_L/R` | 0.07 | 0.55 | 8 fitted + 8 spare | 8.8 | Ø19 / Ø13.6 × 0.5 |
| **Subtotal** | | | | **162.9** | |

## 6. Purchased items

| Item | Spec | Qty | Unit g | Total g |
|---|---|---:|---:|---:|
| Shoulder actuator | **Steadywin GIM6010-8** (variant TBC — see design record §9) | 2 | ~500 | 1000 |
| Wheel actuator | **Steadywin GIM4305-10** | 2 | ~250 | 500 |
| Knee bearing | **6800-2RS, 10 × 19 × 5**, sealed | 4 | 6.5 | 26.0 |
| Main knee spring — original two-leg CAD baseline | Ø19 OD × **2.6 mm wire** × **55 mm free** × ~9.8 active coils, closed & ground, **chrome-silicon ASTM A877/A877M**, shot-peened + preset, **10.45 N/mm**. The active single-leg article owns a yellow OD18 / ID9 × 50 mm spring and has a separate test-only Ø8-pilot cartridge release for controlled, unpowered -8°…+15° ABS observation. Its rate/solid height and final two-leg cartridge remain open. [Spring record](evidence/springs/2026-09-05_reconciliation/) · [test release](evidence/assembly/2026-09-17_abs_spring_mechanical_test/). | 2 | 25.3 | 50.6 |
| Cartridge pivot pin | Ø4 × 32 clevis pin + E-clip (DIN 6799-4) | 4 | 3.8 | 15.2 |
| Knee stop dowel | Ø6 × 9 hardened dowel, h6 | 2 | 2.0 | 4.0 |
| Knee angle sensor | **AS5048A** (or AS5047-class) on a 14 × 14 PCB | 2 | ~2 | 4.0 |
| Encoder magnet | Ø6 × 2.5 **diametric** NdFeB | 2 | 0.53 | 1.1 |
| Flexion bumper | Ø6.2 × 7.5 arc block, PU ~90 A | 2 | <0.1 | 0.2 |
| Extension bumper | Ø6.2 × 3.0 arc block, PU ~90 A | 2 | <0.1 | 0.2 |
| Knee thrust washer | PTFE/POM, Ø22 / Ø16.5 × 0.5 (as required) | 4 | 0.1 | 0.4 |
| Heat-set insert | Voron-style M3 × 5.0; exact owned variant unverified; nominal Ø4.0 ABS receiver failed and the owner selected nominal Ø4.5 on the dedicated ladder | 14 active single-leg (including stand) / 28 two-leg robot | ~0.4 | track from achieved parts; repeat coupon for PA-CF |
| Heat-set insert | Owner-held Kadriick M4 × 8, shoulder root; Ø5.3 ABS bore owner PASS, 2026-09-04 | 6 | — | — |
| Heat-set insert | Owner-held Kadriick M4 × 8, wheel rim joint; Ø5.3 ABS bore owner PASS, 2026-09-04 | 6 | — | — |
| Harness | Ø3.0 high-flex silicone, ≥ 400 mm coiled per shoulder | 2 | ~7 | 14.0 |

## 7. Fasteners

| Size | Where | Qty/leg | Qty/robot |
|---|---|---:|---:|
| **M3 × 8 SHCS** | shoulder plate → motor housing (Ø74 PCD); **not ×10**, which bottoms in the 4.0 mm-deep actuator thread through the 5 mm panel | 8 | 16 |
| M3 × 10 SHCS | output hub → motor output (Ø25 PCD) | 6 | 12 |
| **M3 × 10 SHCS** | cable cover → shoulder-plate inserts, installed from accessible outboard face (Ø88 PCD) | 4 | 8 |
| M4 × 10 SHCS | proximal link root → hub flange (Ø44 PCD) | 6 | 12 |
| **M4 × 8 SHCS** | wheel rim → short wheel-hub inserts (Ø46 PCD) | 6 | 12 |
| **M3 × 6 SHCS** | knee stop arc → proximal arm B inserts | 3 | 6 |
| M3 × 8 SHCS | wheel hub → motor output (Ø27 PCD) | 3 | 6 |
| M2.5 × 12 SHCS | wheel motor → distal wheel-end plate (Ø47.5 PCD) | 6 | 12 |
| M3 × 16 SHCS | encoder bracket → arm B inserts | 2 | 4 |
| M3 × 10 SHCS | chassis frame → side panels (5 per side) | — | 10 |
| **Total** | | **44 + chassis** | **98** |

Fastener mass ≈ **123 g** per robot (model figure).

The former 10-piece M3 row covered only the two proximal arm-B bosses and
omitted both shoulder-plate cover receivers, the active Mode A stand, and every
printed M4 receiving thread. It was not a purchase quantity. Use the canonical
[printed-thread map](MANUFACTURING_CONSTRAINTS.md#threaded-interfaces-in-printed-parts):
the active single-leg ABS article needs **14 owner-supplied Voron-style M3
inserts** before spares, plus **12 of the 30 owner-held Kadriick M4 × 8
inserts**: six shoulder and six wheel. The Ø5.3 ABS ladder station passed and
was promoted through Fusion on 2026-09-04. The shoulder hub insert installation has since passed. The corrected link
requires physical rehearsal; the rim retains its printability hold. See
[ASSEMBLY_VERIFICATION.md](ASSEMBLY_VERIFICATION.md#2026-09-05-access-and-assembly-order-audit).

**Fastener corrections retained in the current release:**

- **Knee stop arc: M3 × 8 → M3 × 6**, on a **30° bolt spacing** (was 20°) on the
  same r = 15 mm circle. *That part is now deleted — this row is kept only because
  it is why the audits exist.*
- **Cable cover, current service-path correction: M3 × 10 from outboard.** The
  four inserts now live through the 5 mm shoulder plate; the removable cover
  has clearance holes. Each screw traverses 6.5 mm of cover, engages 3.5 mm in
  brass and stops 1.5 mm before the inaccessible inboard plate face. This
  supersedes revision 2's M3 × 8 screw driven from inside the chassis.

The later delivered-actuator/rig audit adds one more active correction:
**shoulder motor housing: M3 × 10 → M3 × 8** through the 5 mm panel. The
GIM6010 housing thread is 4.0 mm deep, so ×10 bottoms instead of clamping. This
is Departure 7 in
[`beni_single_leg_rig_design_record.md`](beni_single_leg_rig_design_record.md).

Full account of both defects, with the arithmetic:
[`beni_prototype1_rev2_changes.md`](beni_prototype1_rev2_changes.md) §4.
Blind-hole geometry is now checked automatically by
`beni_lib.audit_fasteners()` and `audit_blind_holes()`.

## 8. Mass roll-up

> ### ⚠ THIS ROLL-UP IS NO LONGER VALID FOR A PRINTED BUILD
> Every figure below was computed with **metal densities**. In particular the
> **`7075-T6 machined … 251.7 g`** and **`Steel machined … 162.9 g`** lines are
> 414.6 g of parts that no longer exist in that form — the hubs and eyes are now
> printed (far lighter), and `Knee_Sleeve_L` and `Knee_Stop_Arc_L` are deleted
> entirely. Therefore **the `3290.1 g` total and the `≈ 210 g` margin are stale
> in the conservative direction** and must not be quoted for a build. They remain
> the correct as-engineered reference for Prototype 1. For a real build mass, use
> [`beni_single_leg_rig_design_record.md`](beni_single_leg_rig_design_record.md) §5.

**Read directly out of the Fusion model** (`beni_lib.mass_by_part()`), with
physical materials and densities assigned per body. Previously every body in
the model carried the default "Steel" and Fusion reported the robot at 8174 g;
this table is now the model's own answer, not a hand calculation beside it.

| Group | Mass g |
|---|---:|
| PA-CF printed (links, side panels, rim, chassis frame) | 565.7 |
| ABS printed (covers, encoder brackets, tray) | 46.4 |
| TPU tyres | 160.1 |
| 7075-T6 machined (hubs, cartridge eyes) — **STALE, now printed** | 251.7 |
| Steel machined (axles, sleeves, stop arcs, rods, shims, carriers) — **STALE, mostly deleted or bought** | 162.9 |
| Bearings (4 × 6800) | 26.0 |
| Springs (2, chrome-silicon) | 50.6 |
| Pins, dowels, magnets, PCBs, bumpers, harness | 38.4 |
| Fasteners (88 modelled screws) | 118.4 |
| **Structure + hardware subtotal** | **1420** |
| Shoulder actuators, 2 × GIM6010-8 @ ~500 g | 1000 |
| Wheel actuators, 2 × GIM4305-10 @ ~250 g | 500 |
| **Mechanical total** | **2920** |
| Battery, 4S 2200 mAh (`Battery_4S2200`) | 250 |
| Compute, IMU, power distribution, wiring (`Chassis_Electronics`) | 120 |
| **ROBOT TOTAL (Fusion)** | **3290.1 g** |
| Design mass | 3500 g |
| **Margin** | **≈ 210 g (6.0 %)** |

The 10 chassis-frame → side-panel M3 × 10 screws (≈4.6 g) are the only
fasteners in the BOM that are not modelled, so the figure above is 3290 g and
the full-hardware figure is ≈3295 g. Both actuator masses are still estimates
and must be confirmed by weighing the delivered units — a 10 % error on the
shoulder pair alone is 100 g, which is half the margin.

The swept-helical `Knee_Spring_L` body carries a derived density that preserves
the specified 25.3 g through regenerated poses. `Shoulder_Cable_Spiral_L` is a
7 g harness envelope; `Battery_4S2200` and `Chassis_Electronics` are mass
placeholders at 250 g and 120 g. All are listed in `beni_lib.MASS_OVERRIDE_G`.

### Mass properties

Mass, CoM and the full inertia tensor — the numbers controls actually needs —
are in **[`beni_prototype1_design_record.md`](beni_prototype1_design_record.md)
§14**, which is the single authoritative copy. Per-link masses and inertia
tensors for all six moving links are in `sim/beni.urdf` and
`sim/beni_inertia.json`.

Reduction targets, in order of return, if the 210 g margin needs to grow:

1. **Wheel rim + tyre = 157.3 g each (314.5 g total).** A spoked tyre section or
   a 5 mm TPU wall instead of 7 mm recovers 60–80 g.
2. **Fasteners at 123 g.** Switching the ~40 non-structural M3/M4 screws to
   aluminium or titanium recovers 40–50 g.
3. **Chassis frame at 70.3 g.** The webs are only lightly lightened; hand-work
   in the Fusion UI is worth ~25 g.
4. **Proximal link at 72.5 g each.** The arms could go from 5.0 to 4.2 mm away
   from the bearing bosses for ~20 g total.

None of these touch frozen geometry.

## 9. Assembly sequence

Order is mandatory where noted. All torque figures are starting values for
PA-CF and 7075 and should be confirmed on a scrap coupon.

### A. Sub-assemblies

**A1 — Knee bearing stack (per leg)**
1. Press `HW_Bearing_6800` into the proximal arm A pocket **from the inboard
   face**, seating it on the Ø17 lip at y = 63.7. Retaining compound.
2. Press the second `HW_Bearing_6800` into arm B **from the outboard face**,
   seating on the Ø17 lip at y = 85.3.
3. Press `Knee_Sleeve_L` into the distal link's Ø16 knee boss bore, with the
   double-D flats aligned to the sagittal plane. It protrudes 1.3 mm each side.
   > **[SUPERSEDED — skip this step.]** `Knee_Sleeve_L` is **deleted**. The Ø16
   > bore is now a nominal Ø10 pin receiver printed directly into
   > `Distal_Link_L`; the owner-selected ABS compensation is Ø10.30 over the
   > serviceable 20.0 mm receiver span.
   > The axle runs in the printed link. See
   > [`beni_single_leg_rig_design_record.md`](beni_single_leg_rig_design_record.md) §4.
4. Fit the two PTFE thrust washers, place the distal link into the proximal
   fork channel and align the bores.
5. **Insert `Knee_Axle_L` from the inboard side** through bearing 1, the sleeve
   and bearing 2. The double-D must engage the sleeve — do not force it.
   > **[SUPERSEDED — no double-D engagement.]** `Knee_Axle_L` is a **bought
   > Ø10 h6 hardened ground dowel pin** with no flats; the double-D was
   > deliberately deleted. The axle simply slides through. Insertion direction
   > and the anti-rotation substitute are in rig design record **§4**.
6. Screw `Knee_Magnet_Carrier_L` into the axle's M4 end with thread locker,
   0.8 N·m. Confirm free rotation and < 0.1 mm axial float.
7. Bond the Ø6 × 2.5 diametric magnet into the carrier pocket.

*This step must precede the cartridge — the axle cannot be inserted afterwards.*

**A2 — Spring cartridge (per leg)**
1. Press `Cart_Guide_Rod_L` into `Cart_Upper_Eye_L`.
2. Slide the spring over the rod onto the upper eye's Ø13.4 spigot.
3. Stack four `Cart_Preload_Shim_L` on `Cart_Lower_Eye_L`'s spigot.
4. Offer the lower eye up, compressing the spring, and align both pivot bores.
   *The assembly separates if either pin is removed — this is what makes the
   spring replaceable.*

**A3 — Wheel (per leg)**
1. Bolt `Wheel_Hub_L` to the wheel motor's output flange, **3 × M3 × 8**
   into the Ø27 PCD threads, 1.2 N·m. Register on the Ø37.3 H8 recess.
   > **[SUPERSEDED — the register is not machined any more.]** `Wheel_Hub_L` is
   > **printed**, so a Ø37.3 H8 recess cannot be held as an H8 fit. It is
   > replaced by a printed register plus **steel washers under the screws and a
   > re-torque schedule** to handle plastic creep. See
   > [`beni_rig_no_machining.md`](beni_rig_no_machining.md) §2.1 and rig design
   > record §4.
2. With the owner-passed Ø5.3 ABS receiver promoted through Fusion, install
   6 × owner-held M4 × 8 inserts while the hub is detached, from the
   corrected wheel hub's **motor face** with a depth stop. Leave 6.0 mm embedded
   and 2.0 mm projecting outboard into the mating rim's six Ø6.0 × 2.2
   reliefs. **RIM PRINT/ASSEMBLY HOLD, 2026-09-04:** resolve its unsupported
   ledges before this following assembly step. Then bolt `Wheel_Rim_L` with
   **6 × M4 × 8** on the Ø46 PCD,
   2.5 N·m. The screws engage 6.0 mm and stop 2.0 mm before the insert's
   motor-side end.
3. Stretch the TPU tyre onto the Ø96 rim seat.

*The 3 hub screws stay reachable through the rim's Ø38 central hole after the
wheel is fully assembled.*

### B. Leg build

1. With `Shoulder_Output_Hub_L` **removed**, bring
   `Chassis_Shoulder_Plate_L` in from the shoulder motor's output/front side.
   Its raised circular cable-spiral lip faces away from the motor and its flat
   panel face faces the stationary housing. The centre opening passes over the
   bare output rotor; the actuator housing stays behind the plate and does not
   pass through it. Bolt the plate to the motor's **front** face,
   **8 × M3 × 8** on the Ø74 PCD, 1.2 N·m. Do not use ×10: it puts 5 mm of screw
   into a 4.0 mm-deep actuator thread and bottoms before clamping. Heads stand
   on the y = 47 face. This
   insertion path is Fusion-verified and recorded in
   [`evidence/shoulder_assembly/2026-08-23_plate_sequence/`](evidence/shoulder_assembly/2026-08-23_plate_sequence/).
2. After the dedicated ABS ladder selects an M3 receiver diameter and that
   result is promoted and reverified through Fusion, fit 4 × M3 heat-set
   inserts flush in the **outboard face of
   `Chassis_Shoulder_Plate_L`**. `Shoulder_Cable_Cover_L` has clearance holes
   only. Fasten it from the accessible outboard face with 4 × **M3 × 10**;
   this joint remains serviceable after the stand or chassis frame is fitted.
3. Feed the harness out through the plate's Ø7 grommet hole at r = 29, lay in
   the spiral (≥ 400 mm, ~3 turns, inner end toward r = 21) and strain-relieve
   at the plate.
4. Bolt `Shoulder_Output_Hub_L` to the motor output: engage the **3 × Ø4 dowel
   pins first**, then 6 × M3 × 10 through the deep counterbores, 1.2 N·m.
5. Pass the harness through the hub's Ø6 port at r = 21 and strain-relieve on
   the hub's outboard face. **Both ends now have strain relief.**
6. After the same ladder-selection and Fusion-promotion gate, fit 5 × M3 heat-set inserts in the proximal
   link's arm B boss (3 for the stop arc, 2 for the encoder bracket).
7. Complete **A1** (knee stack) — proximal link + distal link joined.
8. Fit the two `HW_ClevisPin_D4x32` to install **A2** (cartridge): upper pin at
   U first, then compress and fit the lower pin at Lp. E-clips both sides.
9. Press `HW_DowelPin_D6x9` into the distal arm B at r = 30, protruding
   3.5 mm outboard. Retaining compound.
10. Bond the PU bumpers into the stop arc's outer-layer bays, then bolt
    `Knee_Stop_Arc_L` to the arm B inserts, **3 × M3 × 6**, 1.0 N·m.
    **Check by hand that the knee now stops at −8° and +27°.**
    *M3 × 6, not × 8: an × 8 bottoms out on the bore floor before it clamps.
    The three heads sit 7.765 mm apart on the 30°-spaced r = 15 circle, so a
    2.5 mm hex key reaches each of them without fouling its neighbours.*
    > **[SUPERSEDED — steps 9 and 10 both. Do not build this.]**
    > `Knee_Stop_Arc_L` is **deleted** (it was laser-cut steel) and the Ø6 dowel
    > that engaged its slot goes with it. The **+27° hard stop is now a
    > compression column of bought M5 washers** inside the spring cartridge, with
    > a printed TPU sleeve as the progressive bumper; a printed
    > `RIG_Knee_Stop_Plate_L` keeps the **−8° stop** and a +28° backup. Its
    > engagement angle must be **set by measurement**, not from a drawing,
    > because it depends on the printed eyes' achieved dead length. Full design:
    > [`beni_single_leg_rig_design_record.md`](beni_single_leg_rig_design_record.md) §8.
11. **[HUB PRINT READY / LINK SCREW-LOADING HOLD, 2026-09-04.]** Print the
    corrected Ø4.15 ABS hub with owner-passed Ø5.3 receivers. Install its six
    M4 × 8 inserts from the detached hub's outboard face using a depth stop;
    each occupies the full 8 mm flange. Repeat the unplugged motor fit.
    The final joint specifies **6 × M4 × 10** on Ø44 PCD, but two screw heads
    hit the existing link's internal wall on a straight insertion path. Keep
    the printed link and bearings pending a detached loading rehearsal; do
    not release or torque this joint before an alternate path is demonstrated.
    The six M3 hub screws remain accessible through the Ø34 root opening.
12. Bolt the wheel motor to the distal wheel-end plate, **6 × M2.5 × 12**
    inserted **from the inboard face**, 0.6 N·m. The driver cover nests in the
    plate's Ø41.5 hole and its two M2 screws stay accessible.
13. Route the wheel-motor harness up the distal link, across the knee with a
    service loop sized for −8° … +27°, and into the proximal link's channel.
14. Fit **A3** (wheel).
15. Mount the encoder PCB to `Knee_Encoder_Bracket_L`, then bolt the bracket to
    the arm B inserts, 2 × M3 × 16. Verify the **1.0 mm** magnet-to-die gap.
16. Power up the encoder and confirm it reads monotonically over −8° … +27°.

### C. Disassembly notes (design intent)

- The spring can be changed by removing **one clevis pin** — no need to touch
  the bearing stack, the shoulder or the wheel.
- The wheel motor and its connector come off with the 6 M2.5 screws. Support
  the active leg off the Mode A stand first; the stand blocks the axial rear
  screw/driver path at the nominal pose.
- The shoulder motor's output screws are reachable through the link's root
  access hole; the motor itself comes out after removing the link.
- The knee axle can only be withdrawn inboard, so the cartridge and stop
  hardware must come off first. Remove the encoder bracket before withdrawing
  the knee-stop screw heads; its Ø5 holes provide driver access only.

---

## 10. Recommended print order

For the active single-leg article, retain the accepted shoulder hub and print the Ø4.5 corrected proximal-link replacement in
the [current print queue](README.md#current-print--convenience-link). The
remaining sequence is gated as follows:

1. Corrected `Chassis_Shoulder_Plate_L`, if the fitted plate is the failed Ø4.0
   revision. The released plate uses the owner-selected Ø4.5 receiver; retain
   the already printed clearance-only cable cover.
2. `Proximal_Link_L/R` — the face-flat Ø19.10 bearing fit passed, but the root
   wall obstructed two screw heads and a lightening cut clipped one seat.
   The printed corrected Ø19.15 link passed its six M4 seats but has failed Ø4.0
   M3 pockets. Print the released Ø4.5 replacement and rehearse all six M4 × 10
   heads and both bearings. [Access audit and order](evidence/assembly/2026-09-05_access_fix/).
3. `Distal_Link_L/R` — the received steel pin seized in the provisional nominal
   Ø10 ABS shin bore, and the owner broke that print to recover it. Nominal
   Ø10.25 gave the intended firm-thumb fit in the initial 19.0 mm coupon, and
   the owner selected Ø10.30 while the receiver was expected to span 21.6 mm.
   Fusion's final audit found that span trapped the link inside the bearing
   pockets and corrected the integrated receiver to the clear 20.0 mm fork gap.
   The tangent-corrected bed-ready ABS fit article has passed DFM,
   support-removal, insertion/service-path, cover-clearance and mesh checks.
   Print it and record firm-thumb insertion, hand withdrawal, spin, rock and
   axial play. Retention and encoder coupling remain held.
   A clearance-fit printed ABS pin may be used only to hand-align a fully
   supported mock-up; it does not clear this
   gate and must not carry powered, spring, ground-contact or load testing.
4. The Ø5.3 ABS `Wheel_Hub_L` is available for detached motor fit.
   **Hold `Wheel_Rim_L/R`** until its internal ledge and outer flange have a
   verified printable solution; then rehearse rim/tyre installation.
5. ABS covers and the encoder bracket last (non-critical).

Repeat the **Ø19 bearing-seat coupon** immediately before the later two-leg
PA-CF structural build. PA-CF shrinkage decides its own compensation; do not
copy the ABS value or ream the printed seat.

*Note: the Ø16 sleeve fit named in step 2 and above is now a nominal **Ø10** pin
receiver printed straight into `Distal_Link_L` — `Knee_Sleeve_L` is deleted.
Ø10.25 passed the initial 19.0 mm ABS coupon, the owner selected Ø10.30, and the
serviceable ABS receiver spans 20.0 mm; PA-CF needs a new coupon.
The print order itself is unchanged.*

---

### Density note

Printed-part masses assume the modelled solid volume at full material density.
A part printed with 4 walls and 30 % infill will come out roughly 25–30 %
lighter than tabulated, which is margin, not error. Structural parts
(`Proximal_Link_L`, `Distal_Link_L`, `Chassis_Shoulder_Plate_L`) should be
printed at high infill so the modelled section is actually realised, and their
tabulated mass should be treated as the real figure.

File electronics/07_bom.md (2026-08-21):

# 07 — Bill of Materials and Shopping List

Prices are **2026 indicative single-quantity USD** from Digi-Key / Mouser /
LCSC / hobby retail. Treat them as ±30% and re-check at order time. Anything
marked **[BLOCKED]** must not be ordered until `05_open_questions.md` clears it.

## 0. Order in three waves (+ a Wave 0 for the single-leg rig)

| Wave | When | Why |
|---|---|---|
| **0 — single-leg rig** | Now | **Teensy path, MODE A.** Everything needed for the rig in `fusion_brief_single_leg_rig.md` §5. Mode-B-only items are deferred, not deleted |
| **A — order now** | Today | Long lead or needed for Stages 0–2 of the **two-leg robot**, and unaffected by the open blockers |
| **B — after Steadywin answers B1** | Wheel-driver max bus voltage | Decides 5S vs 6S vs 6S+buck, i.e. the pack and half the power tree |
| **C — after rev-A board bring-up** | Stage 3 | Don't buy five of anything you haven't run once |

## Wave 0 — single-leg rig, MODE A (~$25 electronics, excluding rig hardware)

The rig runs a **Teensy 4.1** (already in hand), two CAN buses at 500 kbps on
breadboarded 3.3 V transceivers, and the knee AS5048A wired directly via SPI — no
satellite node, no custom PCB, no PCB lead time.

**Amended 2026-08-17 — Mode A only, and using hardware already on hand.** Four
changes, each with a reason:
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

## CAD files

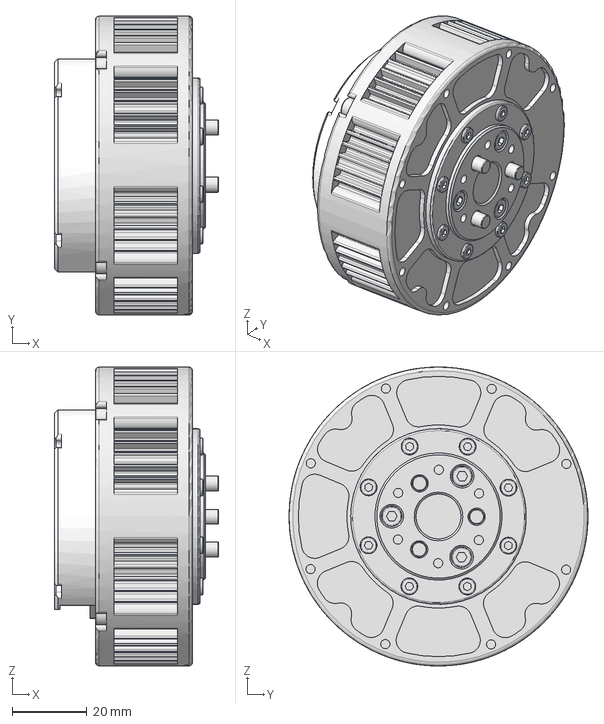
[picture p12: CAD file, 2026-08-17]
CAD Imports/ascii/GIM6010_8.stp
44.0 x 80.0 x 80.0 mm
6010-8_简化_1
V5驱动盖

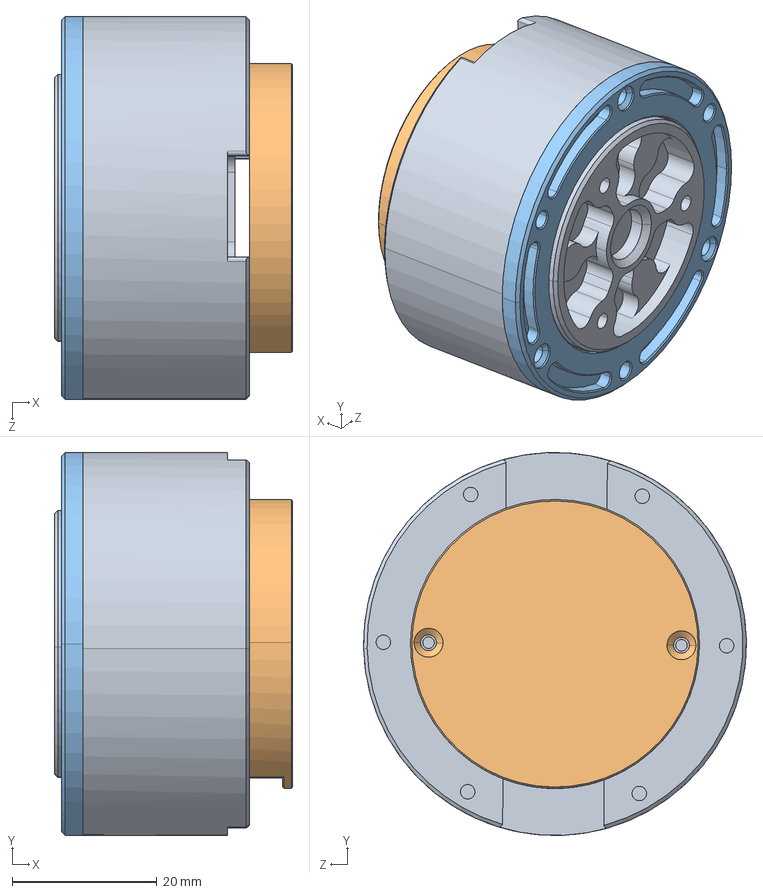
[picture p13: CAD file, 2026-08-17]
CAD Imports/GIM4305-10_带驱动安装 ? _25071701.STEP
33.0 x 53.0 x 53.0 mm
V6SHS_X2_540E673A58F3_X0_-_X2_5B8988C556FE_X0_
X4_X2_540E76D6_X0_
V6_X2_8F74627F76D6_X0_

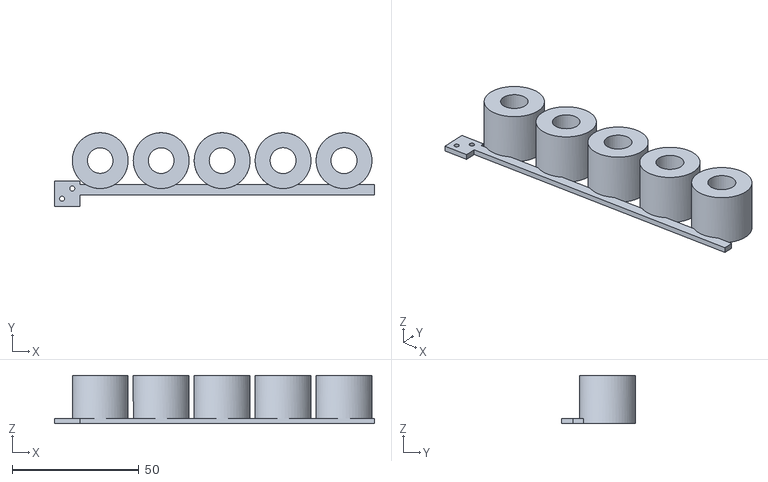
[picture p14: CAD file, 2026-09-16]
evidence/knee_fit/2026-09-15_steel_pin_provisional_shin/ABS_CAL_KNEE_PIN_BORE_LADDER_19MM_PRINTED.stl
126.0 x 29.0 x 19.0

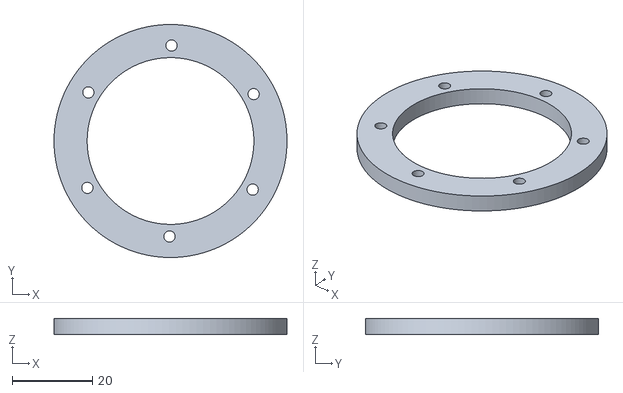
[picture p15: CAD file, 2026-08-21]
first_article_stl/actuator_fit/ABS_FIT_GIM4305_HOUSING.stl
58.0 x 58.0 x 4.00

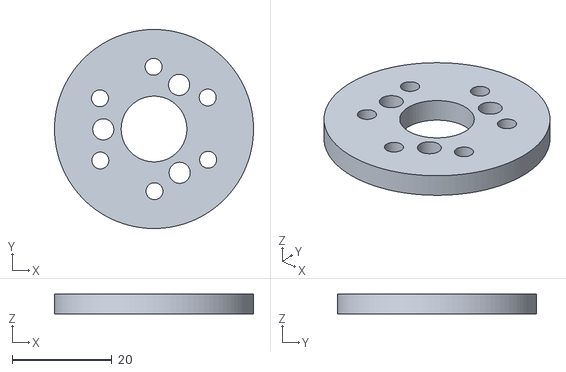
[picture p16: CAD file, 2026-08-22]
first_article_stl/actuator_fit/gim6010_pin_trials/ABS_CAL_GIM6010_OUTPUT_PIN_D4p25.stl
40.0 x 40.0 x 4.00

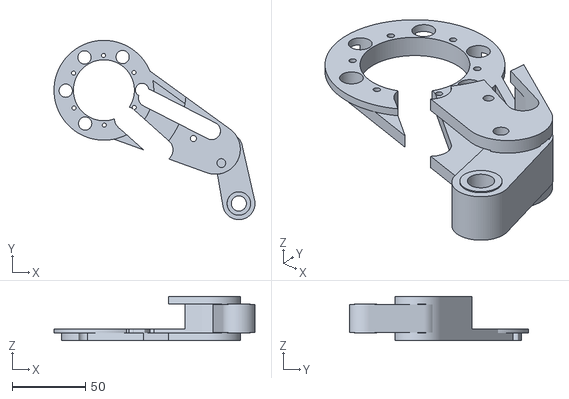
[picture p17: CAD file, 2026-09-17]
first_article_stl/assembly_dry_fit/ABS_FA_Distal_Link_L_D10p30_STEEL_PIN_FIT_PRINT_ORIENTED.stl
136.9 x 122.1 x 30.0

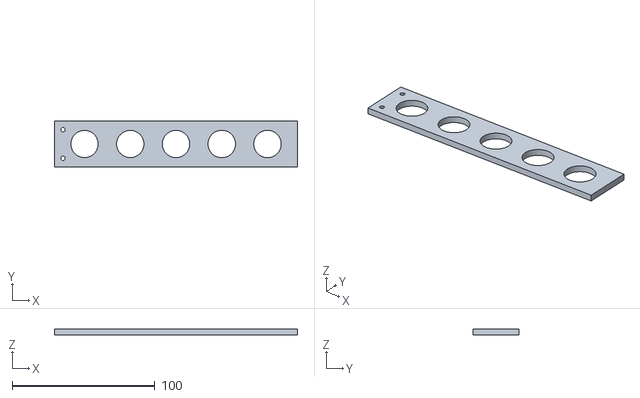
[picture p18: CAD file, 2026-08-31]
first_article_stl/bearing_fit/ABS_CAL_6800_BORE_LADDER.stl
170.0 x 32.0 x 4.00

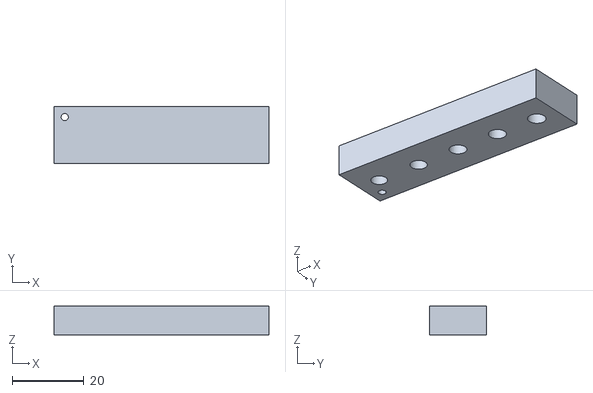
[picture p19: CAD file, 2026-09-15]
first_article_stl/insert_fit/ABS_CAL_OWNED_M3x5_INSERT_POCKET_LADDER_PRINT_ORIENTED.stl
60.0 x 16.0 x 8.00

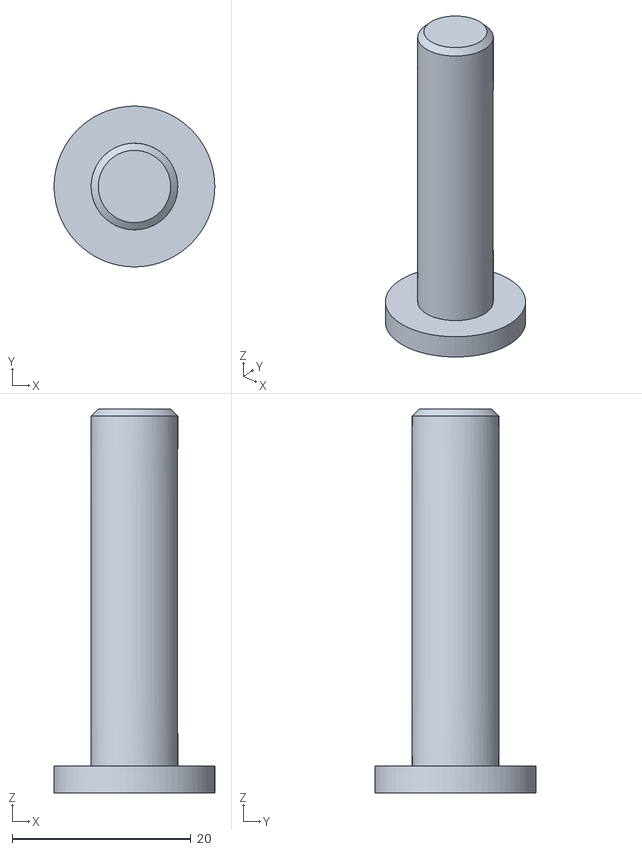
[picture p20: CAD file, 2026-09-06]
first_article_stl/knee_mockup/ABS_MOCKUP_Knee_Alignment_Pin_D9p7_PRINT_ORIENTED.stl
18.0 x 18.0 x 43.0

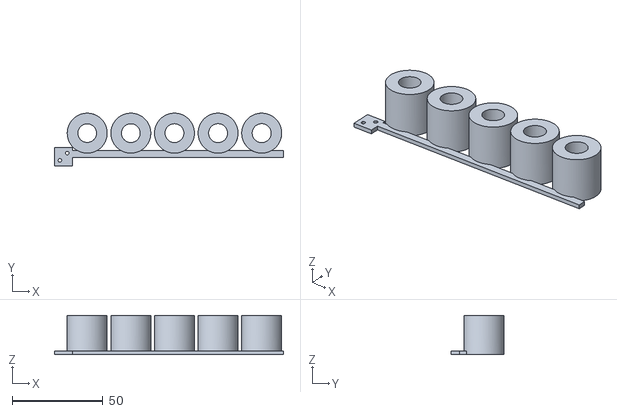
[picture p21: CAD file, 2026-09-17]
first_article_stl/knee_pin_fit/ABS_CAL_KNEE_PIN_BORE_LADDER_PRINT_ORIENTED.stl
126.0 x 29.0 x 21.6

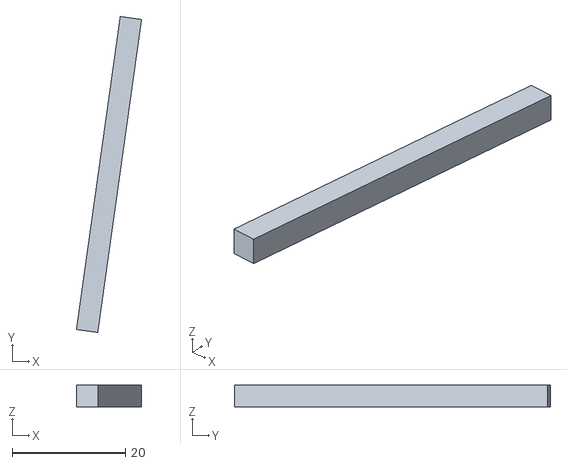
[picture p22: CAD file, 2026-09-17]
first_article_stl/mechanical_spring_test/ABS_TEST_Cart_Guide_Bar_50mm_FLAT_PRINT_ORIENTED.stl
11.5 x 55.7 x 3.80

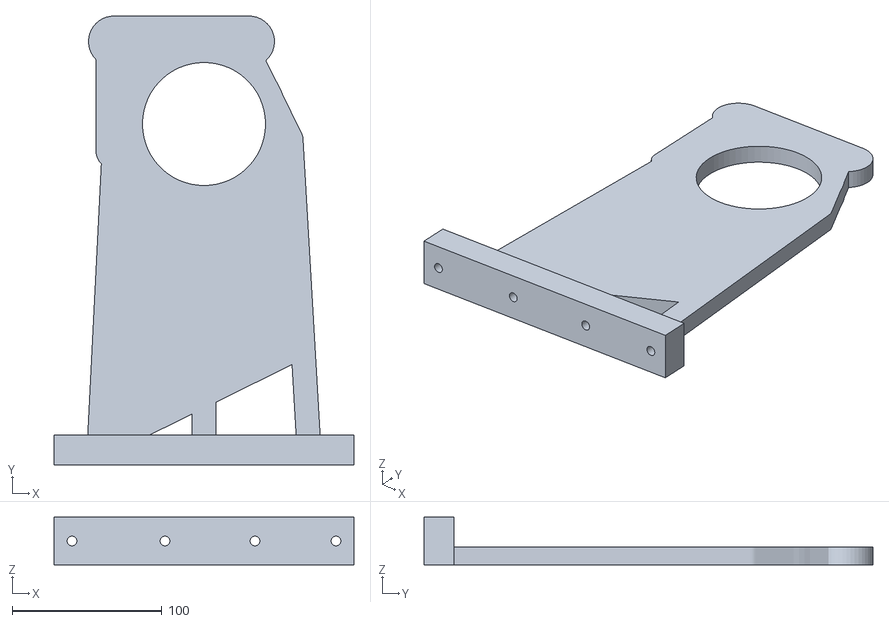
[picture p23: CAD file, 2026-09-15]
first_article_stl/mode_a/ABS_FA_RIG_Stand_M3_INSERTS_PRINT_ORIENTED.stl
200.0 x 299.3 x 32.0

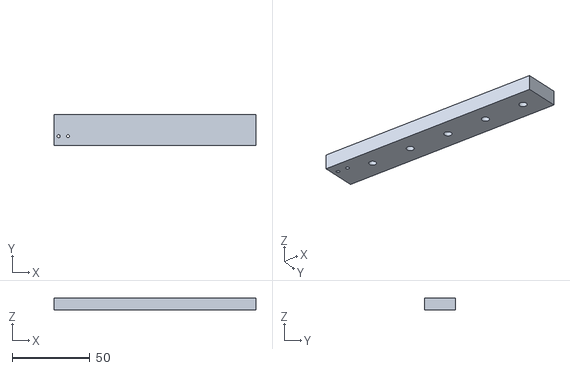
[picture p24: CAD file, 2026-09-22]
first_article_stl/ordered_pin_fit/ABS_CAL_D4x10_ROOT_BLIND_SOCKET_LADDER_PRINT_ORIENTED.stl
130.0 x 20.0 x 8.00

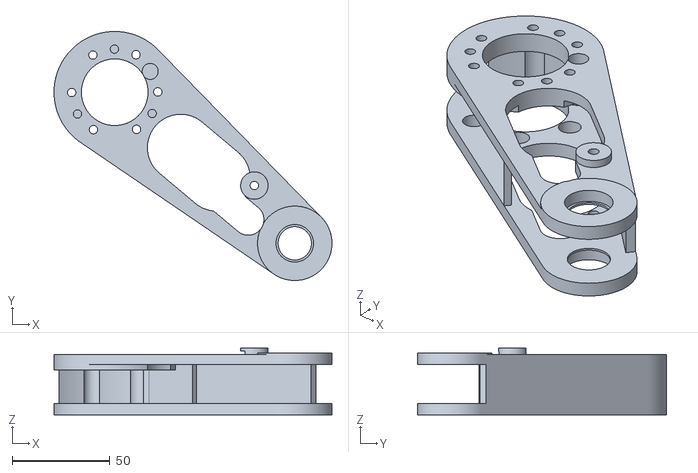
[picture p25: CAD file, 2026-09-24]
first_article_stl/ordered_pin_integration/ABS_PINREV2_Proximal_Link_D19p15_ROOT_D4p30_CLEVIS_D4p30_PRINT_ORIENTED.stl
141.9 x 127.1 x 34.0

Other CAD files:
manufacturing/step/Knee_Sleeve_L.step
print_stl/check_prints/Wheel_Hub_L.stl
print_stl/Proximal_Link_L.stl
rig_stl/reroute/Wheel_Hub_L.stl
archive/laser/Knee_Stop_Arc_L_inner.dxf
archive/laser/Knee_Stop_Arc_L_nest.dxf
archive/laser/Knee_Stop_Arc_L_outer.dxf
archive/laser/RIG_Ballast_Disc.dxf
archive/manufacturing/step/Cart_Guide_Rod_L.step
archive/manufacturing/step/Cart_Lower_Eye_L.step
archive/manufacturing/step/Cart_Preload_Shim_L.step
archive/manufacturing/step/Cart_Upper_Eye_L.step
archive/manufacturing/step/Knee_Axle_L.step
archive/manufacturing/step/Knee_Magnet_Carrier_L.step
archive/manufacturing/step/Knee_Sleeve_L.step
archive/manufacturing/step/Knee_Stop_Arc_L.step
archive/manufacturing/step/Shoulder_Output_Hub_L.step
archive/manufacturing/step/Wheel_Hub_L.step
first_article_stl/actuator_fit/ABS_FIT_GIM4305_OUTPUT.stl
first_article_stl/actuator_fit/ABS_FIT_GIM6010_HOUSING.stl
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

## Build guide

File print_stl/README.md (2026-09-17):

# Beni Prototype 1 — fit coupons and first articles

> ### ⚠ Superseded in places by the single-leg rig build
>
> **3D printed and off-the-shelf parts only, no laser cutting or machining** —
> see [`../MANUFACTURING_CONSTRAINTS.md`](../MANUFACTURING_CONSTRAINTS.md).
>
> - **`Distal_Link_L.stl` is superseded** by
>   [`../rig_stl/reroute/Distal_Link_L.stl`](../rig_stl/reroute/Distal_Link_L.stl).
>   The steel knee sleeve is deleted and its Ø16 bore is now printed into the link
>   as the owner-selected Ø10.30 ABS receiver around the nominal Ø10 pin. **That
>   rig file is currently on DFM hold** pending the post-tangent-fix bed-ready
>   Fusion audit, service path and retention design; do not print either legacy
>   distal file yet.
> - **`check_prints/` is obsolete** — it existed to dry-fit before ordering
>   machining. Use [`../rig_stl/reroute/`](../rig_stl/reroute/) instead.
> - The **`GAUGE_*` coupons below are still exactly right** and were re-measured
>   against the design record feature by feature. Note that the shoulder coupon is
>   only **9.5 mm long** and therefore cannot report the delivered motor's exact
>   overall length. The STEP model supplies the 44.0000 mm nominal dimension;
>   use the real motor and ABS mating article as a functional go/no-go.
>
> Everything else on this page stands. What to print for the rig:
> [`../rig_stl/README.md`](../rig_stl/README.md).

Everything here is exported straight from the verified Fusion assembly
(`Beni_Prototype1`) at High mesh refinement. All STLs are in millimetres and sit
at their assembly coordinates, not centred on the origin — every slicer will
drop them to the bed and centre them for you.

Chiral parts are exported **left-hand only**. Mirror in the slicer for the
right-hand part; there is no separate `_R` file.

> **Revision 2 — 2026-08-08.** Re-exported from the corrected model. The links
> and side panels now carry fillets at every load-bearing re-entrant corner, the
> rim has a tyre bead groove and an inboard retaining flange, and the tyre has a
> crowned tread. Two screw lengths changed — see the hardware list at the bottom.
> Details in [`../beni_prototype1_rev2_changes.md`](../beni_prototype1_rev2_changes.md).

---

## Print in this order

### 1. `GAUGE_Fit_Coupon.stl` — printed; nominal Ø4.0 M3 station failed
The owner printed an ABS coupon with the fixture small parts on September 7.
[Completion record](../evidence/assembly/2026-09-07_small_parts_printed/).
On September 14 the owner reported that the nominal Ø4.0 M3 station is too
small. [Physical result](../evidence/inserts/2026-09-14_m3_coupon_fail/).
This general gauge has only one M3 candidate, so it could not select a replacement
diameter. The owner printed the dedicated Ø4.1–4.5
[M3 insert-pocket ladder](../first_article_stl/insert_fit/) and selected the
largest, unmarked-end station, nominal Ø4.5.
The coupon is 14 cm³, ~25 min; repeat in PA-CF before releasing structural
PA-CF parts.

A 26 × 92 × 8 bar with six through-bores, one for every critical fit in the
robot:

| bore | what it is | target fit |
|---:|---|---|
| Ø19.0 | 6800 bearing seat, proximal arms | light press — bearing enters with thumb pressure, no rock |
| Ø16.0 | **was** the steel knee sleeve's seat in the distal boss — **that bore is now Ø10**, printed straight into `Distal_Link_L`, because `Knee_Sleeve_L` is deleted. Measure it as a general large-bore check only | light press |
| Ø10.0 | knee axle bore — the fit that now matters, on a bought Ø10 h6 × 35 mm dowel pin | light press, not a loose slip — this press is the rig's angular reference |
| Ø6.0 | knee-stop dowel seat | light press |
| Ø4.05 | shoulder-output dowel | slip |
| Ø4.0 | Voron-style M3 heat-set insert pocket | **OWNER FAIL, 2026-09-14: too small; use the dedicated ladder** |

With no calipers, test the bores using the real matching bearings, dowels,
fasteners, and inserts. Record which nominal feature produces the required fit
and use that to set the ABS profile's **hole / X-Y size compensation**. The
result is specific to the material, printer, orientation, and profile; do not
reuse ABS compensation for PA-CF.

For the active Mode A first article, the immediate go/no-go checks are Ø19 with
the real 6800-2RS bearing and Ø10 with a real h6/h5 steel knee pin. The metal
candidates arrived on September 15; quantity, measured diameter and exact
tolerance evidence remain to be verified. One pin passed snugly through both
installed bearings but seized in the provisional shin's nominal Ø10 bore,
forcing the owner to break the printed shin to recover it. That bore is a
**FAIL**. Nominal Ø10.25 then gave the intended firm-thumb fit on the initial
Ø22 × 19.0 mm coupon. The owner selected Ø10.30 while the receiver was expected
to span 21.6 mm. Fusion's final service audit found that copied steel-sleeve
span trapped the link inside the bearing pockets, so v26 uses the clear 20.0 mm
fork gap with 0.8 mm axial clearance per side. The [Ø10.25–Ø10.45 full-span
ladder](../first_article_stl/knee_pin_fit/) remains a conservative optional
diagnostic. Test the candidates through each bearing separately and print the
[released distal fit article](../first_article_stl/assembly_dry_fit/ABS_FA_Distal_Link_L_D10p30_STEEL_PIN_FIT_PRINT_ORIENTED.stl).
Physical fit, retention and encoder coupling remain open.
[Result](../evidence/knee_fit/2026-09-15_steel_pin_provisional_shin/).
A deliberately clearance-fit printed ABS pin may support
hand-alignment work meanwhile, but it cannot release the distal link, establish
the knee-angle datum, or carry powered, spring, ground-contact or load testing.
The Ø16 bore is a superseded sleeve check; Ø6 supports later stop work; the
Ø4.0 M3 result is superseded by the dedicated ladder; and the Ø4.05
shoulder-output result has already been superseded for this
ABS profile by the owner-tested Ø4.15 hub.

**Physical result, 2026-08-31:** the real 6800-2RS bearing does not enter the
nominal Ø19.00 bore with thumb pressure. It starts only under table/clamp force,
so this is a **FAIL**, not permission to clamp it home. The owner then printed the indexed
[`ABS_CAL_6800_BORE_LADDER.stl`](../first_article_stl/bearing_fit/ABS_CAL_6800_BORE_LADDER.stl)
whose two small holes mark the Ø19.05 end; the five main bores are Ø19.05,
Ø19.10, Ø19.15, Ø19.20 and Ø19.25 moving away from those markers. Test from
smallest to largest. **Ø19.10 PASSed** and the face-flat full-depth Ø19.10 link
accepted both bearings on 2026-09-02, but the owner found the production seats
slightly tighter than preferred. **Ø19.15 is now preferred for future ABS
links**: easier thumb insertion with no perceptible movement. The existing
Ø19.10 bearing fit remains accepted, but its separately identified root-access
and screw-seat defects now require the corrected Ø19.15 link in the
[current queue](../README.md#current-print--convenience-link). PA-CF is deferred to the later
two-leg structural build and must be recalibrated then.

**This one print de-risks every other print.** Don't skip it — the Ø19 bearing
seats and the Ø10 knee-axle bore are the two fits that will otherwise waste a
whole link.

### 2. The two positive motor stand-ins
These reproduce the motor envelopes for checking mating CAD when no motor is
available. They are not negative sockets and cannot be test-fitted onto the
delivered motors. Now that the motors are in hand, they are optional: design a
small negative ABS mating coupon in Fusion, or print the actual mating part in
ABS, for the physical go/no-go.

- **`GAUGE_Shoulder_Motor_Interface.stl`** (31 cm³, Ø78 × 10)
  Replicates the GIM6010-8's mating geometry exactly as measured from the STEP:
  the Ø78 front face, **8 × Ø2.5 pilots on the Ø74 PCD** (tap M3), the Ø46 rotor
  step, the Ø34 pilot boss, the output face 3.5 mm proud with **6 × Ø2.5 pilots
  on the Ø25 PCD** and **3 × Ø4.05 dowel holes on the Ø20.4 PCD**.
  Press three Ø4 × 8 steel dowels into those holes and you have a working
  stand-in for the motor's anti-rotation pins.

- **`GAUGE_Wheel_Motor_Interface.stl`** (31 cm³, Ø53 × 33)
  Replicates the GIM4305-10: the full Ø53 × 33 envelope, **6 × Ø2.0 pilots on
  the Ø47.5 PCD** (tap M2.5), the Ø40.4 driver-cover boss, the bearing gland,
  and the output flange Ø37 at the far end with **3 × Ø2.5 on the Ø27 PCD**.
  Note it is the *full length* on purpose — use it to confirm the wheel drum
  clears the motor and that the driver cover nests in the distal plate's Ø41.5
  pocket.

### 3. `check_prints/` — obsolete
Its premise was "print these in PLA before ordering any machining." **There is no
machining.** Print the real printed parts instead:
[`../rig_stl/reroute/`](../rig_stl/reroute/).

### 4. Structural PA-CF parts — only after step 1
Print one of each first and dry-fit before committing to the second set.
The four files are `Chassis_Shoulder_Plate_L.stl`, `Distal_Link_L.stl`
(**use `../rig_stl/reroute/Distal_Link_L.stl` instead** — see the banner),
`Proximal_Link_L.stl` and `Chassis_Frame.stl`. **Orientations, footprints and the
rationale for each are in the BOM `§1`** —
[`../beni_prototype1_bom_and_assembly.md`](../beni_prototype1_bom_and_assembly.md).
Don't re-derive them here.

"On edge" matters for the links: it puts primary bending loads in the print
plane and makes the 20 mm spring channel a through-slot, so nothing needs
internal support. Every part in this design is single-shell — there are no
enclosed cavities anywhere, so no print should ever need trapped support.

Print the structural parts at **high infill** (≥ 60 %, 4+ walls). The mass
figures in the BOM assume the modelled section is actually realised; a
lightly-infilled 5 mm knee arm is not the part that was analysed.

### 5. Wheel and covers — last, nothing depends on them
| file | material | note |
|---|---|---|
| `Wheel_Rim_L.stl` | ABS now; PA-CF later | **PRINTABILITY HOLD, 2026-09-04.** The M4 Ø5.3 ABS coupon passed, but Fusion found a 14 mm unsupported internal ledge and an outer flange overhang in the web-down orientation. Do not print this mesh or the held bed-ready candidate. Resolve the overhangs while preserving the six Ø6.0 × 2.2 insert-tip reliefs and mating surfaces. |
| `Wheel_Tyre_L.stl` | TPU 95A | Ø110 × 30; stretches onto the Ø96 rim seat |
| `Shoulder_Cable_Cover_L.stl` | ABS | Clearance part: 4 × Ø3.4 through-holes, **no inserts**. The released replacement shoulder plate has four owner-selected Ø4.5 M3 receivers. Use M3 × 10 screws from the accessible outboard face. |
| `Knee_Encoder_Bracket_L.stl` | ABS | 2 × M3 clearance holes; the receiving inserts live in the proximal-link arm-B boss |
| `Electronics_Tray.stl` | ABS | flat panel |

---

## What the first-article campaign validates

- Every bore fit and the slicer compensation (step 1).
- Both motor bolt patterns and the output-side dowel/screw patterns (step 2).
- The spring cartridge in the 20 mm channel, both pivot pins, and that removing
  one clevis pin frees the spring.
- Driver access to all 32 audited screws.
- That the wheel drum clears the wheel motor and the distal plate.

## What you cannot validate yet

- Actual spring rate and preload — needs the real spring on a press.
- Anything load-bearing. PLA stand-ins prove geometry, not strength.
- Motor bolt-thread engagement depth, and the exact GIM6010-8 variant, bus
  voltage and driver configuration (still to confirm with the supplier).
- Harness bend radius in the shoulder clock-spring cavity — needs the real
  Ø3.0 high-flex cable.

## Hardware worth ordering now so it's on the bench for the dry fit

4 × 6800-2RS bearings · 4 × Ø4 × 32 clevis pins + E-clips · 3 × Ø4 × 8 dowels
per shoulder gauge · M3/M4/M2.5 SHCS assortment · 4 × Ø22/Ø16.5 × 0.5 PTFE
thrust washers. Heat-set insert sizes and quantities are no longer repeated
here: use the canonical
[printed-thread map](../MANUFACTURING_CONSTRAINTS.md#threaded-interfaces-in-printed-parts),
which records the owned Voron-style M3 family and the current M4 hub holds.

Screw lengths: the cable cover is now **M3 × 10 from the outboard face into
shoulder-plate inserts**. This supersedes revision 2's inaccessible inboard
M3 × 8 arrangement. The knee-stop screws (M3 × 6 at 30° spacing) went with the
deleted stop arc; historical reasoning is in
[`../beni_prototype1_rev2_changes.md`](../beni_prototype1_rev2_changes.md) §4.

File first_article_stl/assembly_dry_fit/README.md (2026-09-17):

# ABS shoulder and proximal-link assembly articles

## Ø10.30 shin/distal steel-pin fit article — released 2026-09-16

Print one
[`ABS_FA_Distal_Link_L_D10p30_STEEL_PIN_FIT_PRINT_ORIENTED.stl`](ABS_FA_Distal_Link_L_D10p30_STEEL_PIN_FIT_PRINT_ORIENTED.stl)
in ABS. Import it unchanged: the broad inboard source face is already on the
bed, and the Ø10.30 knee-pin bore is bed-normal like the accepted coupon.

The initial integrated receiver copied the former steel sleeve's 21.6 mm span.
Fusion proved that geometry cannot be assembled: its Ø16 end lands extend
0.8 mm into both bearing pockets and trap the shin in every radial direction.
The released receiver stays within the clear 20.0 mm proximal-fork gap. It is
still 1.0 mm longer than the printed Ø10.25 coupon and retains the owner's
Ø10.30 choice, while leaving 0.8 mm nominal axial clearance to each bearing.

Use the tuned enclosed ABS profile: 0.20 mm layers, 4 walls, 5 top/bottom
layers and 30% infill. Paint or place normal supports only beneath these four
regions:

1. the Ø16 knee-receiver annular underside;
2. the raised knee web;
3. the wheel-end underside; and
4. the open channel ceiling.

For the 0.20 mm profile use at least **0.4 mm top/bottom support distance** and
**0.6 mm XY distance**. Block support from the complete knee bore, cartridge
and stop bores, motor-cover opening, motor screw holes and motor mounting face.
Remove the three lower support groups toward the bed and the channel support
through its open side. Inspect all four supported surfaces before assembly.

Support both links on the bench and keep both motors and the spring disconnected.
With both 6800 bearings installed in the proximal link, translate the detached
shin straight into the fork along the verified +X path; reverse that motion for
service. Insert the steel pin from the inboard side using thumb pressure only.
The article passes when the pin enters fully, withdraws by hand, has no free
spin or perceptible radial rock in the printed receiver, and the 0.8 mm nominal
clearance on each side does not produce unacceptable axial play. Do not hammer,
clamp, sand or polish the pin to make the result pass.

Fusion checked 241 link-path poses and 101 pin-path poses with zero modeled
interference. The STL is a closed 5,990-triangle manifold and matches the
native solid volume within 0.014%. The complete Mode A eight-check regression
passed on the corrected geometry before the v25 save; the v26 support-gap
revalidation left that source geometry unchanged.
[Fusion release evidence](../../evidence/knee_fit/2026-09-16_distal_d10p30_release/).

This is a **steel-pin fit and assembly-path release**. The current knee collar
does not retain the pin, and the magnet carrier/encoder coupling is not yet
released. Do not attach the spring, power either motor, put the wheel on the
ground or structurally load the joint.

## Corrected proximal link — Ø4.5 replacement released 2026-09-14

The owner confirmed proper seating of all six hub screws on the printed Ø4.0
revision on September 7. [Physical result and photo](../../evidence/assembly/2026-09-07_owner_mockup/).
That result remains valid for the M4 access correction, but its five M3 pockets
are the failed Ø4.0 size. Print one replacement
[`ABS_FA_Proximal_Link_L_D19p15_M4_ACCESS_FIXED_PRINT_ORIENTED.stl`](ABS_FA_Proximal_Link_L_D19p15_M4_ACCESS_FIXED_PRINT_ORIENTED.stl)
in ABS; this file uses the owner-selected Ø4.5 M3 receiver diameter. The owner successfully printed the corrected Ø4.15 shoulder hub and
installed its Ø5.3 M4 inserts; retain that hub.

Fusion found two wall-obstructed M4 head paths and one incomplete screw seat
on the old link. The replacement clears both paths and shortens the large
lightening opening to support every head fully. The five knee M3 mouths are
clear. The replacement also uses the already-selected Ø19.15 ABS bearing
preference; this is now a required geometry reprint rather than a change made
only for bearing preference.

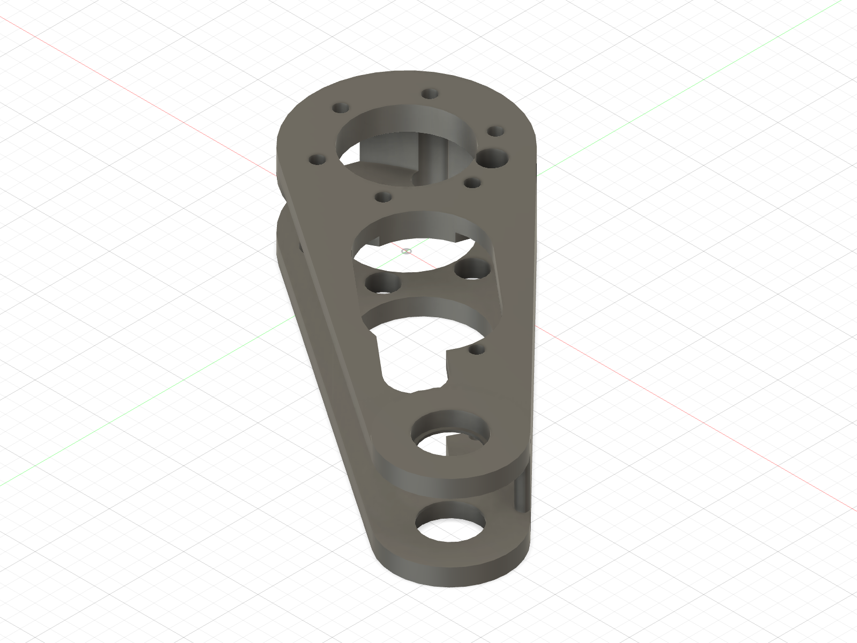
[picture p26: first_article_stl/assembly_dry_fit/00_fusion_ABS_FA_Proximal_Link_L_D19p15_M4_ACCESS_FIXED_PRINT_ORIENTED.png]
Corrected link exported in its bed orientation


## Print and acceptance

- Quantity **1, ABS**. Import the supplied orientation unchanged: outboard
  arm/bearing face down, bearing and insert axes vertical. No scaling or hole
  compensation. Use the same enclosed ABS profile as the passed coupons:
  0.20 mm layers, 4 walls, 5 top/bottom layers and 30% infill.
- Disable supports. The 20 mm channel and root-pad ceilings bridge. Preview
  those bridges and inspect the printed undersides, both Ø17 bearing lips and
  every counterbore floor. A brim is permitted if the tuned profile uses one.
- Before attachment, each of the six **M4 × 10** screws must pass freely through
  its access hole and rest flat in its counterbore. No filing, forcing or screw
  pull-down to compensate for a failed print.
- Fit both 6800 bearings from their respective open faces using thumb pressure
  on the outer race. They must sit square and have no perceptible radial rock.
  Reuse bearings from the old link only if removed without damage.
- Install five M3 × 5 inserts in the new link's Ø4.5 pockets only after checking
  the print for cracks, bulging and bridge debris. Do not install them in the
  prior printed Ø4.0 revision. The six M4 inserts belong in the accepted hub.
- Keep the motor unplugged, support the knee end, attach the link and
  finger-start all six M4 screws. Every head must clamp flat. Remove/refit once
  and record the physical result.

[Exact audit, remaining holds and evidence](../../evidence/assembly/2026-09-05_access_fix/)
· [Shoulder picture guide](../../docs/assembly/shoulder_to_proximal_link.md)
· [Receiver map](../../docs/assembly/heatset_receiver_map.md)

## Adjacent available articles

The [cable cover](ABS_FA_Shoulder_Cable_Cover_L_CLEARANCE_PRINT_ORIENTED.stl)
and [wheel hub](ABS_FA_Wheel_Hub_L_OWNED_M4x8_D5p30_PRINT_ORIENTED.stl) are now
printed, along with the front cable post and general fit gauge.
[September 7 completion record](../../evidence/assembly/2026-09-07_small_parts_printed/).
Cover/post/harness fit and wheel-hub insert installation/detached motor fit
remain pending; no repeat print is currently requested.

The gauge's Ø4.0 M3 station failed, and the owner selected Ø4.5 on the dedicated
[M3 ladder](../insert_fit/). Print the re-exported stand separately. Print the
Ø4.5 shoulder plate if the fitted plate is the prior Ø4.0 revision or lacks
suitable cover-insert receivers. Use the documented bed orientations and insert gates.
The wheel rim is still **DO NOT PRINT** because of its unsupported ledges. Use
the released Ø10.30 distal article above for the real steel-pin fit. The knee
collar, magnet carrier and encoder coupling retain their release gates. The
older [supported knee mock-up batch](../knee_mockup/) remains historical
evidence for its loose printed alignment pin only.

The new [front cable post](../mode_a/ABS_FA_RIG_Cable_Post_A_COVER_MOUNT_PRINT_ORIENTED.stl)
fits outside the cover. Use two **M3 × 12** at the upper cover positions; the
lower two remain M3 × 10. Fit panel/stand and housing screws before post/cover,
then fit the link. Remove the link before servicing the cover. Verify the real
tie/harness through the eye and hand-check clearance before any powered step.

## Physical-fit history

The old Ø19.10 face-flat link accepted both real bearings on 2026-09-02. That
bearing result remains valid evidence; its outer fastener access and one seat
are superseded by the new link. Historical files below are **not the current
print queue**:

- [Ø19.10 full-depth owner report](../../evidence/knee_fit/2026-09-02_proximal_link_full_depth/)
- [Old bearing geometry manifest](proximal_d19p10_fusion_manifest.json)
- [Old bearing-path verification](proximal_d19p10_path_verification.json)
- [Old print-orientation record](proximal_d19p10_print_orientation_manifest.json)
- [Original wall-obstruction finding](../../evidence/inserts/2026-09-04_m4_coupon_pass/fusion_paths_and_print_audit.json)

Earlier on-edge printing caused a non-round bearing seat and damage during
support removal. Retain the corrected face-flat orientation: no support may
contact a bearing seat, retention lip, mating surface or service passage.

The ABS article is for supported dry assembly and, after all leg/fixture and
electronics gates pass, wheel-clear current-limited self-weight commissioning.
No spring preload, torque-arm load, stall/proof, traction or drop testing.
Repeat critical coupons before the later PA-CF structural build.

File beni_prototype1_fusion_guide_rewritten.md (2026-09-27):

# Beni-Like Wheeled Biped — Prototype 1 Fusion Design Guide

> ### ⚠ BUILD CONSTRAINT, 2026-08-12 — two rules below are overridden
>
> **3D printed and off-the-shelf parts only. No laser cutting, no machining.**
> See **[`MANUFACTURING_CONSTRAINTS.md`](MANUFACTURING_CONSTRAINTS.md)**.
>
> The frozen kinematics (§4–§9 geometry, §17's freeze list) are **untouched** and
> remain the authority. Two *material and process* rules are not satisfiable and
> have been overridden with reasons:
>
> | Rule | Status |
> |---|---|
> | §9 — "Use a metal output hub/adapter where torque is transferred. **Do not use a printed friction-fit shaft/hub interface**" | **Overridden.** `Wheel_Hub_L` is printed and takes torque by friction at 3 × M3, ≈20.7 N·m capacity against a ≈4–5 N·m peak. Mitigations are mandatory, not optional: a steel washer under every screw head, and re-torque after the first hour then every ~10 hours, because preload in plastic creeps. `beni_rig_no_machining.md` §2.1 |
> | §10 — "Use metal for … **motor output hubs**" | **Overridden** for the same part and for `Shoulder_Output_Hub_L`, which is printed **plus three bought Ø4 × 10 hardened dowel pins**. The pins are what keep the constraint honest: the printed register alone sees 63 MPa at proof load against PA-CF's ~40–50 MPa shear, and the pins move the shear into steel. `beni_rig_no_machining.md` §2.1 |
>
> Everything else §10 asks for in metal is still metal, just **bought** rather than
> machined: the knee axle is a Ø10 hardened dowel pin, the cartridge pivots are Ø4
> clevis pins, and the final hard-stop surface is a stack of M5 washers loaded in
> compression (design record §8).

## 1. Mission and agent behavior

Design a **physically buildable first prototype that reproduces the mechanics of Mondo Robotics' current Beni-style serial leg**, using the supplied STEP files for:

- Shoulder: **Steadywin GIM6010-8**
- Wheel: **Steadywin GIM4305-10**

The design is not complete until it is manufacturable, printable, assemblable, serviceable, fully fastened, and collision-checked through its full motion.

### Work autonomously
Continue until the complete robot and all validation checks are finished.

Do **not** stop after normal phases to ask whether to continue. Do not ask for approval of routine engineering choices. If a detail is unspecified:

1. inspect the supplied STEP geometry and existing model;
2. make a conservative, practical engineering assumption;
3. record the assumption;
4. continue.

Only ask the user if work is genuinely blocked by missing/corrupt source geometry or irreconcilable requirements.

If subagents are available, use them **serially only**. Every subagent must inspect and verify the previous phase before modifying the model.

---

# 2. Architecture to reproduce

**[LEGACY PASSIVE PROTOTYPE; SUPERSEDED FOR ACTIVE-KNEE R2A]** The reconstruction
used for the existing Fusion model was:

**body → active rotary shoulder → proximal link → passive spring-loaded cylindrical knee/elbow → distal link → driven wheel**

This serial biped morphology remains intentional. **[SUPERSEDED 2026-09-25]**
The instruction prohibiting an active knee does not apply to R2A: teardown
evidence now shows that Beni's knee is actively driven from the hip through a
crank and link. Preserve this passive model as history and develop R2A in a separate
Fusion copy. See
[`docs/design/active_knee_revision2_plan.md`](docs/design/active_knee_revision2_plan.md).

## Shoulder
- Shoulder motor is fixed to the body.
- The complete leg rotates about the shoulder output.
- Require **at least one complete 360° usable mechanical sweep**.
- Target Fusion joint range: approximately **-185° to +185°**.
- This means 360° total usable motion, **not necessarily unlimited multi-turn rotation**.
- The shoulder must move in either direction for normal posture, jumping, flips, recovery, and self-righting.

## Knee
**[LEGACY PASSIVE PROTOTYPE]** The knee is passive. There is no knee actuator in
this historical model. R2A replaces it with a remote active knee.

The knee contains the compliant spring mechanism and sits between the proximal
and distal leg links. **[SUPERSEDED 2026-09-25]** The mechanism below is an
engineered Prototype 1 implementation; teardown evidence now shows it is not
Beni's actual actuation architecture.

## Wheel
The wheel motor is fixed to the distal link and independently drives the wheel.

---

# 3. Important mechanical behavior

**[LEGACY PASSIVE PROTOTYPE]** Do not model or reason about this passive knee as
if it were commanded by shoulder position. R2A instead requires a derived
shoulder/knee-motor coordinate map for the belt transmission.

### Shoulder rotation does NOT automatically compress the knee
If the wheel can move freely, rotating the shoulder mainly rotates the whole bent leg. The passive knee changes angle only when forces acting through the distal link create enough moment about the knee to overcome the spring.

### Normal "squat" / ride-height change
For a deliberate low stance, the shoulder rotates the whole bent leg while the driven wheel rolls to accommodate the fore-aft motion. The passive knee should remain near its load-dependent equilibrium.

Do **not** require a deep static knee fold as the normal squat mechanism.

### Knee compression
Knee flexion occurs when wheel/ground forces create knee moment. This is strongest during:
- dynamic jump preload,
- takeoff,
- landing,
- terrain impacts.

Coordinated wheel torque can influence knee loading, but the design must not depend on the wheel motor statically forcing the knee to full compression.

### Jump
**[LEGACY HYPOTHESIS; SUPERSEDED FOR R2A]** The passive model used this jump
explanation:

**During a jump, the shoulder actuators rotate the leg assemblies so the lower/distal legs and wheels are driven rapidly downward against the ground. The resulting ground reaction loads and compresses the passive spring knees while accelerating the body upward.**

The phrase "drive the legs downward" describes the jump action. It does not limit shoulder rotation direction.

### Landing
**[LEGACY HYPOTHESIS; SUPERSEDED FOR R2A]** The passive knee was intended to
handle the first impact/compliance and store/return energy. R2A must derive a
coordinated active shoulder-and-knee landing controller and load case instead.

**[LEGACY RATIONALE]** This followed the general Ascento lesson that passive leg
compliance can be combined with active hip/shoulder damping. It does not size or
validate the R2A active-knee landing controller.

---

# 4. Frozen Prototype 1 kinematics

Use these as global Fusion parameters unless the motor STEP geometry proves a direct physical conflict.

| Parameter | Value |
|---|---:|
| Design mass | 3.5 kg |
| Static load, each leg | ~17.2 N |
| Wheel OD | 110 mm |
| Proximal link L1 | 120 mm |
| Distal link L2 | 120 mm |
| Nominal proximal-link angle | +50° from downward vertical |
| Nominal distal-link angle | -50° from downward vertical |
| Nominal wheel position | directly below shoulder |
| Passive knee extension stop | φ = -8° |
| Passive knee nominal | φ = 0° |
| Main flexion design point | φ = +25° |
| Physical flexion hard stop | φ = +27° |
| Structural link/knee width budget | ~28 mm |

### Knee-angle convention
With the proximal link fixed, positive knee flexion rotates the distal link farther away from vertical:

**distal angle = -50° - φ**

Do not reverse this convention accidentally.

### Fusion geometry checkpoints

With the shoulder fixed at nominal:

| Knee φ | Vertical wheel compression | Fore-aft wheel displacement |
|---:|---:|---:|
| -8° | -12.0 mm | 11.6 mm |
| 0° | 0 | 0 |
| +5° | 8.3 mm | 6.4 mm |
| +10° | 17.1 mm | 12.0 mm |
| +15° | 26.4 mm | 16.8 mm |
| +20° | 36.1 mm | 20.8 mm |
| +25° | **46.1 mm** | **24.0 mm** |

At nominal, shoulder-to-wheel vertical distance is approximately **154.3 mm**.

These numbers are verification checkpoints. If the Fusion model does not reproduce them within normal CAD rounding error, stop that phase, find the geometry error, and fix it before continuing.

---

# 5. Passive knee spring mechanism

Use a **guided compression-spring cartridge spanning the knee**, packaged inside the bent-leg/knee envelope and hidden/protected by a removable cylindrical knee cover.

This is not claimed to be Beni's exact hidden internal linkage. It is the Prototype 1 implementation.

## Anchor geometry

Let K be the knee axis.

- Proximal/upper cartridge pivot radius from K: **Ru = 36 mm**
- Distal/lower cartridge pivot radius from K: **Rl = 54 mm**
- Included angle between K→pivot vectors at nominal: **110°**
- As the knee flexes by φ, included angle becomes approximately **110° - φ**

The assembly may be rotated as a whole around K to package it, but the radii and relative angle must remain unchanged.

### Cartridge geometry checkpoints

| Knee φ | Pivot eye-to-eye length | Spring moment arm about K |
|---:|---:|---:|
| -8° | 77.70 mm | 22.09 mm |
| 0° | 74.44 mm | 24.54 mm |
| +10° | 69.91 mm | 27.39 mm |
| +20° | 64.90 mm | 29.95 mm |
| +25° | 62.23 mm | 31.12 mm |

Extension-to-+25° cartridge stroke: **15.47 mm**.

This rising moment arm is deliberate. Do not "simplify" the anchors into geometry with a nearly constant or falling moment arm.

---

# 6. Spring target

Prototype target:

- Compression spring
- Rate: **~10.45 N/mm**
- Force at -8°: **~30 N**
- Force at nominal: **~64 N**
- Force at +25°: **~192 N**

Expected per-leg vertical ground capacity:

| Knee φ | Approx. ground force | Equivalent static load |
|---:|---:|---:|
| -8° | 8.3 N | 0.49 g |
| 0° | 17.2 N | 1.00 g |
| +5° | 23.1 N | 1.35 g |
| +10° | 29.4 N | 1.71 g |
| +15° | 36.2 N | 2.11 g |
| +20° | 43.6 N | 2.54 g |
| +25° | **51.5 N** | **3.00 g** |

The effective wheel rate is mildly progressive, approximately **0.71 to 0.80 N/mm** through useful compression.

### Starting physical spring envelope
Model a replaceable spring approximately:

- OD: **19 mm**
- Wire: **2.6 mm**
- Mean coil diameter: ~16.4 mm
- Free length: **~55 mm**
- Active coils: ~9.8
- Closed/ground ends preferred
- Central guide rod
- Target material for repeated jumping: **ASTM A877/A877M valve-spring-quality chrome-silicon**, preferably shot-peened/preset

A228 music wire is acceptable for early prototypes.

Do not use ordinary ASTM A401 as the preferred repeated-jump spring material; the current ASTM A401 scope explicitly says it is not intended for high-cycle fatigue applications.

Treat the spring specification as **replaceable/tunable**, not a permanently trapped part.

---

# 7. Knee construction

Preferred starting hardware:

- **10 mm steel knee axle**
- **2 × 6800-series sealed bearings, 10×19×5 mm**
- Double-shear printed/metal-supported joint geometry
- Metal spacers/washers as required
- No printed axle
- No plain printed rotating bearing surface

### Spring cartridge
Use:
- ~5 mm steel guide rod,
- sliding spring seat with low-friction polymer bushing,
- metal spring seats where concentrated loads occur,
- ~4 mm steel cartridge pivot pins/shoulder screws,
- removable preload shims rather than a bulky adjustment mechanism,
- removable cartridge without removing the shoulder motor.

The spring line of action sits approximately **22–31 mm from the knee axis** through the useful range. Preserve clearance between the spring envelope, bearing stack, links, and fasteners using real solid geometry.

### Stops
- Extension: compliant contact just before **-8°**, then a positive mechanical stop.
- Flexion bumper begins around **+20°**.
- Main spring design point: **+25°**.
- Metal-backed positive hard stop: **+27°**.
- Never use coil bind as the travel stop.
- Never use a thin printed tab as the final crash load path.

Provide a replaceable polyurethane/TPU-style bumper pocket. Exact bumper compound is a bench-test tuning item.

### Knee sensing
Add an absolute knee-angle sensor provision:
- coaxial diametric magnet,
- AS5048A / AS5047-class magnetic encoder or equivalent,
- sensor fixed to one side, magnet rotating with the other,
- protected strain-relieved cable path.

The passive knee angle is required for state estimation, spring-deflection estimation, simulation matching, and landing control.

---

# 8. Shoulder module

Use the supplied GIM6010-8 STEP as the dimensional source of truth.

Do not use the stale assumption of 9 N·m rated / 25 N·m peak as motor capability.

Current Steadywin published GIM6010-8 variants are roughly:
- 24 V version: 5 N·m rated, 11 N·m stall
- 48 V versions: 4.6–5.4 N·m rated, about 17.2–17.9 N·m stall

Exact variant/driver must be verified separately.

### Mechanical design rule
Proof-design the shoulder mount/output interface around **~25 N·m** as a structural screening load even if the current motor cannot continuously produce it.

Keep the proximal link close to the motor output bearing to reduce cantilever. Only add an outboard support bearing if the STEP geometry allows a clean, non-overconstrained implementation.

### 360° wiring
Prototype 1 requires a full ~370° physical joint range, not unlimited spinning.

Preferred order:
1. inspect STEP for usable central/hollow cable routing;
2. if unavailable, use a high-flex harness/service loop routed close to the axis;
3. model the cable envelope through -185° to +185°;
4. add strain relief on both sides.

Do not add a slip ring unless unlimited repeated multi-turn rotation becomes an actual requirement.

---

# 9. Wheel module

Use the supplied GIM4305-10 STEP as the dimensional source of truth.

- Wheel OD: **110 mm**
- Use a metal output hub/adapter where torque is transferred.
- Do not use a printed friction-fit shaft/hub interface.
- The motor and connector must remain removable after the robot is assembled.
- Route wheel-motor wiring across the passive knee with sufficient service loop for -8° to +27°.

The ~28 mm budget applies primarily to the structural leg/knee package; do not corrupt the motor mounting geometry merely to force the wheel motor itself inside an impossible width.

---

# 10. Materials and FDM rules

## PA-CF — preferred for load-bearing parts
Use PA-CF for:
- shoulder motor mounts,
- proximal links,
- distal links,
- knee clevis/housing,
- wheel motor structural mount,
- major chassis load paths.

## ABS — acceptable for noncritical parts
ABS is appropriate for:
- covers/fairings,
- electronics trays,
- cable guides,
- guards,
- fit-check prototypes,
- low-load chassis panels.

Do **not** default to ABS for the shoulder output structure, knee bearing housings, hard-stop structure, or highly loaded links when PA-CF is available.

## Metal where required
Use metal for:
- knee axle,
- cartridge pivot pins,
- motor output hubs,
- bearing sleeves/spacers as needed,
- final hard-stop pins/surfaces,
- any small feature carrying concentrated impact load.

## Printability
For every printed component:
- explicitly choose print orientation;
- prefer primary bending loads in the print plane;
- avoid trapped supports;
- avoid inaccessible horizontal cavities;
- avoid thin material around bearings/inserts;
- split a part if that materially improves printing, strength, or assembly;
- model support-removal access where internal support would otherwise be required.

For structural joints, prefer **through-bolts + locknuts** over heat-set inserts. Use heat-set inserts mainly for covers and repeatedly serviced low-load parts.

---

# 11. Structural load cases

Use these as screening cases, not as claims of exact landing physics.

1. **Static:** 17.2 N vertical per wheel.
2. **Main knee operating point:** ~51.5 N vertical per wheel at +25°.
3. **Structural crash/proof screen:** apply up to approximately **275 N at one wheel** (about 8 g × total robot mass) through realistic worst-case directions/poses.

Check:
- knee axle/bearing loads,
- link bending,
- shoulder mount,
- motor-output adapter,
- wheel-motor mount,
- hard-stop path.

For printed PA-CF parts, do not treat isotropic Fusion FEA as final proof. Use conservative material properties, inspect stress concentrations, and require bench load/drop tests before jumping.

---

# 12. Landing energy design

A 3.5 kg robot dropped 100 mm reaches approximately **1.4 m/s** before contact.

The passive knee alone should not be expected to absorb the entire landing while remaining compliant. The current two-knee spring system provides useful impact shaping but the shoulder must participate.

Design intent:

**passive knee compliance + active shoulder yielding/damping + progressive final bumper**

Do not:
- lock the shoulder mechanically during landing;
- make the main knee spring extremely stiff just to survive a drop;
- add an oil damper in Prototype 1 unless testing shows active damping is insufficient.

Keep provisions modular so a small physical damper can be added later if needed.

---

# 13. Serial Fusion workflow

Use real Fusion components, not a monolithic body.

Run these phases **serially**:

### Phase 1 — Reference audit
- Import both STEP motors as immutable reference components.
- Measure mounting patterns, pilot/registers, shafts/outputs, connector envelopes, body envelopes.
- Create a global parameter table.
- Verify measurements before proceeding.

### Phase 2 — Shoulder module
Design individually:
1. chassis motor interface,
2. shoulder mount,
3. output hub/adapter,
4. shaft/bearing support if used,
5. cable routing envelope.

Assemble and sweep -185° to +185° before proceeding.

### Phase 3 — Proximal link
Create as a separate printable component. Add real fastener interfaces and service access.

### Phase 4 — Knee bearing stack
Create axle, bearings, spacers, clevis/tongue geometry and hardware. Verify actual assembly order.

### Phase 5 — Distal link
Create as a separate component with knee and wheel-motor interfaces.

### Phase 6 — Spring cartridge
Build all cartridge parts individually:
- pivots,
- guide rod,
- moving seat,
- fixed seat,
- spring,
- preload shims,
- retainers.

Check the eye-to-eye checkpoint table at -8°, 0°, +10°, +20°, +25°.

### Phase 7 — Stops and encoder
Add extension stop, progressive flexion bumper, hard stop, encoder magnet/sensor and wiring.

### Phase 8 — Wheel module
Motor mount, hub, wheel envelope, fasteners and wiring.

### Phase 9 — Complete one-leg assembly
Only now assemble the full leg.

Verify all combinations of:
- shoulder -185° to +185°,
- knee -8°, 0°, +10°, +20°, +25°, +27°,
- full wheel envelope.

Do not duplicate the leg until this passes.

### Phase 10 — Second leg and chassis
Duplicate/adapt the validated leg and design the chassis around the proven modules.

### Phase 11 — Manufacturing/assembly audit
For every component verify:
- print orientation,
- support accessibility,
- bearing insertion,
- motor insertion/removal,
- screw-driver access,
- nut access,
- cable installation,
- spring replacement,
- disassembly sequence.

### Phase 12 — Red-team audit
Deliberately search for:
- collisions hidden in normal view,
- impossible fastener installation,
- captive nuts/bearings/springs,
- parts that cannot be inserted after neighboring parts exist,
- trapped support,
- cable pinch/twist,
- inaccessible motor connectors,
- hard stops that load weak printed tabs,
- insufficient bearing-seat wall thickness,
- duplicate/interfering solids.

Fix every failure and rerun the affected checks.

---

# 14. Required motion/configuration checks

Create named Fusion positions/configurations for:

1. **Nominal stand** — knee 0°, wheel below shoulder.
2. **Shoulder squat** — knee near 0°, shoulder rotated enough to lower body while wheel rolls; verify no body/wheel collision.
3. **Knee extension** — -8°.
4. **Knee 10° compression**.
5. **Knee 20° compression / bumper engagement**.
6. **Knee 25° design compression**.
7. **Knee 27° hard stop**.
8. **Jump-drive pose** — shoulder oriented so active rotation can drive wheel/downstream link into the ground.
9. **Self-righting sweep** — full shoulder sweep with realistic knee/wheel envelopes.

Important: a deep static knee-fold squat is **not** a required normal behavior. At +25°, the spring geometry corresponds to roughly 3 g vertical loading; that pose is mainly a dynamic preload/landing state.

---

# 15. Acceptance checklist

Do not declare completion until all are true:

- full 360° shoulder sweep is physically possible;
- shoulder wiring survives the full sweep;
- nominal wheel axis is directly below the shoulder;
- Fusion reproduces the knee kinematic checkpoint table;
- Fusion reproduces the spring eye-to-eye checkpoint table;
- passive knee is a real revolute joint with real spring hardware;
- spring cannot escape or coil-bind before hard stop;
- knee bearings/axle are physically assemblable;
- spring cartridge can be replaced;
- bumper and hard stop have real load paths;
- knee encoder physically fits and can be wired;
- wheel motor and connectors are removable;
- every screw has tool access;
- every nut/washer/spacer has an installation path;
- every printed part has an explicit viable print orientation;
- no inaccessible support is required;
- one-leg assembly passes all collision sweeps before duplication;
- complete robot passes all shoulder/knee collision combinations;
- PA-CF is used for primary load paths unless a documented reason justifies another material;
- structural proof cases have been reviewed;
- BOM and assembly sequence are complete.

---

# 16. Deliverables

The Fusion project must contain:

- clean named components,
- global parameter table,
- immutable motor references,
- individual manufacturable parts,
- shoulder subassembly,
- knee subassembly,
- wheel subassembly,
- validated single-leg assembly,
- complete two-leg robot,
- real fasteners/bearings/shafts/spacers,
- functional shoulder/knee/wheel joints,
- cable-routing envelopes,
- named motion-check positions,
- exploded view or explicit assembly sequence,
- BOM.

Also provide a short engineering note with:
- assumptions made,
- unresolved risks,
- exact motor variant still needing electrical verification,
- spring items requiring supplier confirmation,
- recommended print order,
- recommended static load tests,
- recommended low-energy drop tests before any powered jump.

---

# 17. Do not change these without demonstrating a failure

For the historical passive Prototype 1, preserve:

- serial Beni-like morphology;
- active 360° shoulder;
- passive spring knee;
- L1 = L2 = 120 mm;
- ±50° nominal link geometry;
- -8° to +27° passive knee range;
- Ru 36 mm / Rl 54 mm / 110° nominal spring-anchor geometry;
- ~10.45 N/mm replaceable main spring target;
- late-travel progressive bumper;
- active shoulder damping as part of landing strategy;
- PA-CF for primary printed load paths;
- no active telescoping leg;
- no Ascento-style parallel linkage;
- **[SUPERSEDED FOR R2A]** no active knee;
- no slip ring unless unlimited multi-turn shoulder rotation is actually required.

---

# Research basis / known uncertainty

The following were checked when this guide was rewritten:

- Mondo Robotics Beni product/spec page:
  https://mondorobotics.com/
- Mondo's early/current prototype development:
  https://www.reddit.com/r/MondoRobotics/comments/1uh7l10/early_prototypes_vs_current_build_the_rd_process/
- Mondo's parallel-leg vs biped discussion:
  https://www.reddit.com/r/robotics/comments/1rd6gin/we_built_both_parallel_leg_and_bipedal_versions/
- Mondo's older parallel-leg prototype:
  https://www.reddit.com/r/MondoRobotics/comments/1rxuuyu/before_there_were_legs_there_was_this/
- Mondo RL/sim-to-real notes:
  https://www.reddit.com/r/MondoRobotics/comments/1szuepv/our_rl_journey_so_far_what_we_learned_what_broke/
- The Verge hands-on Beni description:
  https://www.theverge.com/gadgets/962538/mondo-robotics-beni-robot-dog-preview
- Ascento paper:
  https://arxiv.org/abs/2005.11435
- Steadywin GIM6010-8 official page:
  https://www.steadywin.cn/en/pd.jsp?fromColId=0&id=116
- Steadywin GIM4305-10 official product page:
  https://www.steadywin.cn/pd.jsp?id=9
- ASTM A877/A877M high-fatigue chrome-silicon spring wire:
  https://store.astm.org/a0877_a0877m-17.html
- ASTM A401/A401M current scope:
  https://store.astm.org/a0401_a0401m-24.html

**[SUPERSEDED 2026-09-25]** A public teardown now exposes the architecture
(frame review 2026-09-27): a hip-coaxial crank drives the knee through a link,
and a body-fixed motor drives a hip-coaxial ring through a short toothed belt.
The dimensions, ratios and load ratings remain unknown; the belt marking is
recorded in the evidence note. The passive cylindrical knee and two-pivot compression-spring
cartridge in this guide are a historical engineered reconstruction, not a
reconstruction of Beni's actual actuation. See the
[teardown evidence note](evidence/reference/2026-09-25_beni_teardown/).

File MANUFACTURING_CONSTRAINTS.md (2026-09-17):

# Manufacturing constraints

**Authoritative. Read before adding any part to any build in this project.**

Stated by the project owner, 2026-08-12.

---

## The rule

> **3D printed parts and off-the-shelf parts only.**
> **No laser cutting. No machining.**

A manifold STL is not by itself a printable release. Print-axis dimensional
control and support-removal requirements are governed by `CLAUDE.md` hard rule
12.

"Off the shelf" means a catalogue item you can order and fit as-is: fasteners,
dowel pins, washers, shims, bearings, linear rail and blocks, aluminium
extrusion, springs, magnets. Cutting bought stock to length with a hacksaw is
fine. Anything that needs a mill, a lathe, a waterjet or a laser is not.

## What this rules out

| Not allowed | Was used for |
|---|---|
| Laser-cut sheet | `Knee_Stop_Arc_L`, `RIG_Ballast_Disc` |
| Milled / turned parts | the ten families in `archive/manufacturing/machined_parts_spec.md` |
| Ground flats, keyed features, reamed precision bores in metal | `Knee_Axle_L`'s double-D, `Knee_Sleeve_L` |

## Where each affected part went

For the single-leg rig, every one of these is resolved. Nothing is outstanding.

| Part | Was | Now | Where it is written up |
|---|---|---|---|
| `Shoulder_Output_Hub_L` | 7075 machined | **printed** + 3 bought Ø4 × 10 dowel pins + M4 inserts | `beni_rig_no_machining.md` §2.1 |
| `Wheel_Hub_L` | 7075 machined | **printed** + steel washers + a re-torque schedule | `beni_rig_no_machining.md` §2.1 |
| `Cart_Upper_Eye_L`, `Cart_Lower_Eye_L` | 7075 machined | **printed**, measured, real dimension fed back to the spring model | `beni_rig_no_machining.md` §2.4 |
| `Knee_Magnet_Carrier_L` | steel | **printed**, runout measured on an indicator | rig design record §4 |
| `Knee_Axle_L` | 4140 ground, double-D | **bought** Ø10 h6 hardened ground dowel pin | rig design record §4 |
| `Knee_Sleeve_L` | steel, double-D bore | **deleted** — its Ø16 bore becomes a nominal Ø10 pin receiver printed into `Distal_Link_L`; Ø10.25 passed the initial 19.0 mm ABS coupon, the owner selected Ø10.30, and the serviceable ABS receiver spans 20.0 mm with 0.8 mm bearing clearance per side | rig design record §4 |
| `Cart_Guide_Rod_L` | ground steel | **bought** Ø5 × 50 hardened shaft | rig design record §9 |
| `Cart_Preload_Shim_L` | shim stock | **bought** Ø19/Ø13.6 × 0.5 shim washers | rig design record §9 |
| **`Knee_Stop_Arc_L`** | **laser-cut 3 mm steel, 45 HRC** | **deleted.** The +27° hard stop is now a **compression column of bought M5 washers** inside the spring cartridge, with a printed TPU sleeve as the progressive bumper; `RIG_Knee_Stop_Plate_L` (printed) keeps the −8° stop and a +28° backup | **rig design record §8** |
| **`RIG_Ballast_Disc`** | **laser-cut 3 mm steel** | **`RIG_Ballast_Pot` × 2**, printed cups filled with off-the-shelf steel shot — **now [DEFERRED — MODE B] (2026-08-17): the Mode A build has no vertical slide, so there is nothing to ballast. The substitution stands if Mode B is ever built; the shot need not be bought now** | **rig design record §5** |

**Amended 2026-08-17 — the rig build is Mode A only.** This does not change any
substitution above; it changes only what has to be printed *now*. Deferred with
Mode B: `RIG_Rail`, `RIG_Blocks`, `RIG_Carriage`, `RIG_Index_Post`,
`RIG_Index_Bar`, `RIG_Mode_Pin`, `RIG_Bumpers`, `RIG_Ballast_Pot`. Added:
**`RIG_Stand`**, printed, which reacts the shoulder's own 11.00 N·m stall / 25.00
N·m proof yaw torque at a **42.00 mm** overhang and therefore **must be clamped to
the bench, not weighted** — see `fusion_agent_guide_mode_a.md`. The stand is fully
inside this constraint: printed part plus bought bench clamps, no machining, no
laser cutting.

## Threaded interfaces in printed parts

**Updated 2026-09-14: the owner confirmed the Ø5.3 ABS station passed all M4 × 8
installation and cooled-retention checks. Fusion verifies that diameter in both
documents. The nominal Ø4.0 M3 general-gauge station failed physically; the
owner then selected the largest, unmarked-end station on the dedicated ladder,
nominal Ø4.5. Fusion verifies Ø4.5 throughout the active ABS M3 receiver family.
The two hubs are ABS first-article print releases. The final tyre-compatible
rim has a separate printability hold; a simplified no-tyre shell is released
only for the suspended September 17 mechanical test. The printed corrected proximal link
passed all six M4 screw seats, closing its reported root-access/seating failure;
replace it with the released Ø4.5-receiver revision before M3 installation.**
Physical evidence: [M4 coupon PASS](evidence/inserts/2026-09-04_m4_coupon_pass/),
[M3 Ø4.0 FAIL](evidence/inserts/2026-09-14_m3_coupon_fail/),
[M3 Ø4.5 selection](evidence/inserts/2026-09-14_m3_coupon_pass/),
and [corrected-link assembly PASS](evidence/assembly/2026-09-07_owner_mockup/).
This is the canonical insert map. The
owner's received assortments are indexed at
[`evidence/inserts/2026-09-02_received/`](evidence/inserts/2026-09-02_received/).
The same information is shown visually in the
[`docs/assembly/heatset_receiver_map.md`](docs/assembly/heatset_receiver_map.md).

The M3 design family is the owner-reported Voron-style insert. The exact
AliExpress order variant still needs to be recorded. The general gauge's sole
nominal Ø4.0 candidate was too small in the owner's ABS result. On the dedicated
Ø4.1/4.2/4.3/4.4/4.5 × 6.0 mm blind-pocket ladder, the owner reports that the
largest pocket works best. Production ABS receivers now use nominal Ø4.5. This
is a qualitative selection without a photograph, measured printed diameter, or
separate spin/pull result; repeat it for the later PA-CF profile. The mixed
Kadriick case contains 30 × M4 × 8 and
25 × M4 × 10 inserts. Its label gives M4 thread pitch 0.7 mm, `d1=5.5 mm` and
`d2=5.0 mm`, but it does not unambiguously define the printed-hole diameter.
The same-profile ABS ladder tested Ø4.9/5.0/5.1/5.2/5.3 through bores. The
owner selected Ø5.3 and confirmed all acceptance checks. Repeat critical
coupons before the later PA-CF structural build.

| Printed thread destination | Qty, active ABS single leg | Insert / receiving feature | Current design status |
|---|---:|---|---|
| `Chassis_Shoulder_Plate_L`, cable-cover joint | 4 | Voron-style M3; owner-selected Ø4.5 through the 5.0 mm plate | **ABS RELEASED.** Replace a fitted prior Ø4.0 plate before insert installation. The removable cover has Ø3.4 clearance holes and four M3 × 10 screws enter from its accessible outboard face. They engage 3.5 mm and stop 1.5 mm before the inboard plate face. When fitting revised cable post A, its 2 mm thickness requires M3 × 12 at the two upper positions; the lower two remain ×10. |
| `Proximal_Link_L` arm-B boss | 5 | Voron-style M3; owner-selected Ø4.5 × 5.0 blind pockets (3 stop-plate + 2 encoder-bracket) | **ABS REPLACEMENT RELEASED.** The printed Ø19.15 access-fixed link passed its bearings and six M4 screw seats but has the failed Ø4.0 pockets. Replace it with the verified Ø4.5 revision before M3 installation. |
| `RIG_Stand` panel interface | 5 | Voron-style M3; owner-selected Ø4.5 × 6.0 blind pocket for a 5.0 mm insert | **ABS RELEASED.** Fusion verified all five spans, surrounding geometry, print orientation, clean STL and zero stand interference. The depth retains 1.0 mm insertion space and a 6.0 mm printed floor. |
| `Shoulder_Output_Hub_L` root flange | 6 | Owner-held Kadriick M4 × 8; owner-selected Ø5.3 through the full 8.0 mm flange | **OWNER HUB INSERT INSTALLATION AND CORRECTED-LINK SIX-SCREW SEATING PASS.** Retain the new Ø4.15 hub with Ø5.3 receivers and corrected link. M4 × 10 link screws have 6.2 mm engagement and 1.8 mm end clearance. The owner confirms all six M4 screws work properly on the replacement. |
| `Wheel_Hub_L` rim joint | 6 | Owner-held Kadriick M4 × 8; owner-selected Ø5.3 through the 6.0 mm hub | **ABS HUB PRINTED; INSERT/MOTOR FIT PENDING; FINAL TYRE RIM HELD.** [September 7 completion](evidence/assembly/2026-09-07_small_parts_printed/). Install from the motor face: 6.0 mm embeds and 2.0 mm projects outboard. The final rim’s six Ø6.0 × 2.2 reliefs retain 0.25 mm radial and 0.20 mm axial envelope clearance, with a Ø38 opening and 1.0 mm ligament. M4 × 8 rim screws have 6.0 mm engagement and 2.0 mm end clearance. Its internal ledge and outer flange still need a verified overhang solution. The separately released no-tyre shell preserves this hub interface and Ø96 drum only for the wheel-clear, unpowered mechanical test. |

The active ABS article consumes **14 M3 inserts** before spares: 4 shoulder
plate + 5 proximal-link boss + 5 stand. It also consumes **12 of the 30 owned
M4 × 8 inserts**: six shoulder and six wheel. M4 × 10 was rejected because it
would add 2.0 mm more projection/relief without improving either joint; changing
these torque joints to M3 was rejected because it would reduce the specified
fastener size and mismatch the existing M4 clearance patterns. The owner elected to retain M4 on 2026-09-04. The M3 and M4
ABS ladders are in
[`first_article_stl/insert_fit/`](first_article_stl/insert_fit/).

Future/deferred interfaces remain visible rather than silently inheriting the
active quantities:

| Printed thread destination | Scope | Status |
|---|---|---|
| `Chassis_Frame`, 5 per side | two-leg build | **SOURCE UPDATED / DEFERRED.** Ten Ø4.5 × 6.0 blind M3 pockets sit in local Ø10 × 6.5 bosses and passed the master Fusion audit. Repeat the coupon for the future PA-CF profile before print release. |
| Optional proximal-link satellite-PCB boss, 2 × M2 per leg | two-leg build / electronics CR-4 | **OPEN DESIGN.** The boss does not exist yet and may be deleted if the final motor-controller architecture reads the knee encoder directly. If retained, select one of the owned M2 insert lengths by coupon and model its pocket before the boss is released. |
| `RIG_Carriage`, 5 × M3 | **[DEFERRED — MODE B]** | **SOURCE UPDATED / DEFERRED.** The builder inherits Ø4.5, but the stripped carriage was not rebuilt or released. Rebuild it in Fusion and repeat the coupon for its eventual material/profile when Mode B returns. |
| `RIG_Carriage`, 4 × M4 ballast studs | **[DEFERRED — MODE B]** | **SOURCE UPDATED / DEFERRED.** The builder inherits the owner-selected Ø5.3 ABS diameter for four through receivers and the full 8 mm insert. Rebuild and verify the deferred carriage through Fusion when Mode B returns; no carriage print is released now. |
| `RIG_Knee_Collar_L` | active knee | **UNRELEASED RETENTION DESIGN — DO NOT PRINT.** The current 3 mm collar does not overlap the Ø10 pin and its Ø2.5 hole is axial, not a working radial set-screw receiver. A clamp collar also cannot be selected from CAD alone because the 35 mm pin allocation leaves no proven free shaft. The first nominal Ø10 ABS shin bore seized and was broken for recovery; the owner selected Ø10.30 for the corrected receiver. Measure the recovered pin and real assembled stack before choosing retention. This is not an insert interface. |

Do **not** add inserts to clearance parts. `Shoulder_Cable_Cover_L` is now a
clearance part; its receiving inserts are in `Chassis_Shoulder_Plate_L`.
`Chassis_Shoulder_Plate_L` also fastens to the GIM6010's metal housing threads;
`Shoulder_Output_Hub_L` fastens to the GIM6010's metal output threads;
`Distal_Link_L` and `Wheel_Hub_L` fasten to the GIM4305's metal threads.
`Knee_Encoder_Bracket_L`, `RIG_Knee_Stop_Plate_L`, and `Wheel_Rim_L` carry
clearance holes; their receiving inserts belong in the proximal link or wheel
hub as identified above. The rim's six larger recesses clear projecting insert
ends and are not receivers. No active printed joint calls for an M2 or M5
insert.

## The one place this cost real margin

Everything above is a lateral move or an improvement except the knee hard stop.

The steel arc worked because its slot ends were **conformal** — a 3.1 mm *concave*
radius bearing on a Ø6 dowel, about 257 MPa at the 534 N crash load. Nothing
printed or off-the-shelf reproduces a concave 3.1 mm steel face, and every convex
substitute reverts to Hertzian line contact at **1.0–2.0 GPa**. That is why the
stop was moved into the spring cartridge as a compression column instead of being
substituted in place: a column has no contact-stress problem at all.

What it costs, honestly:

- the working stop is **inside the cartridge and not inspectable** without pulling
  a clevis pin;
- it reacts through two **printed** spigot faces at 9.9 MPa rather than a hardened
  steel slot end — a factor of 8 below the material, but plastic where there used
  to be steel in the final crash path;
- its engagement angle depends on the printed eyes' achieved dead length, so it
  must be **set by measurement after step 6**, not from a drawing.

Full reasoning, the Hertzian numbers for every substitute considered, and the
verification sweep: `beni_single_leg_rig_design_record.md` §8.

## Scope

The constraint governs **what gets built**. It does not invalidate the design
records that describe the two-leg robot as originally engineered:

- `archive/manufacturing/machined_parts_spec.md` still correctly specifies the ten
  machined families **as they were designed**. It is not a shopping list for the
  rig build — see its own banner.
- `beni_prototype1_design_record.md` and `beni_prototype1_bom_and_assembly.md`
  describe Prototype 1 with machined hubs and axles. That is history, and the
  mass and load numbers in them are still the reference.

If the two-leg build later gets access to a shop or a laser, the retired steel
arc files are preserved under `archive/laser/`.

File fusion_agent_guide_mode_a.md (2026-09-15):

# Fusion Agent Guide — the Mode A build

**Written 2026-08-17.** This is the CAD handoff. It exists so an agent with Fusion
access can pick up the `Beni_SingleLegRig` model and finish the **Mode A** build
without re-deriving anything and without reading five other documents first.

**There is exactly one part to design: `RIG_Stand`.** Everything else in the Mode A
part set is already modelled and verified. The stand replaces `RIG_Base` +
`RIG_Column` + `RIG_Braces` + `RIG_Carriage` — four parts collapsing into one — and
no `build_rig_stand()` exists in `rig_lib.py` yet.

**Read §1 and §6 before you open the model.** §6 describes a *reproducible* way to
silently corrupt the assembly, and it fires on operations that are house style in
this codebase.

---

## 0. What you must not do

Three rules from `CLAUDE.md` that constrain this task specifically:

1. **3D printed and off-the-shelf parts only. No laser cutting, no machining.** The
   stand is a printed part plus bought bench clamps. If a design problem seems to
   need a machined bracket, solve it another way.
2. **Never invent, recompute or round an engineering number.** Every figure in this
   guide is copied from `rig_calc.py`, the design record or the brief. If you need a
   number that is not here, get it from `rig_calc.py` — do not derive it.
3. **Prefer editing builders over hand-editing the model.** Write
   `build_rig_stand()` in `rig_lib.py`. A stand that exists only as hand-modelled
   geometry cannot be re-run, and this project's models are reproducible by design.

And one from the brief: **do not distort the design to shrink the overhang.** 42.00
mm is already 67 % of Mode B. Prefer short stiff joints over clever ones.

---

## 1. The scope decision, in one paragraph

The rig was designed with two modes. The brief's §1 says *"Mode A is Mode B with a
pin through the carriage"*: Mode A bolts the shoulder rigid for actuator
characterisation, encoder cal, CAN, latency, torque and **spring F₀/k**; Mode B puts
the shoulder on a 400 mm vertical MGN12 rail ballasted to 1.645 kg for the bounce
mode and the drop series. **The build is Mode A only.** Mode B is **deferred, not
cancelled** — every Mode B figure is retained under a `[DEFERRED — MODE B]` marker
so the slide can be built later without re-deriving it.

**Mode A still measures the spring.** Brief §6 assigns step 6 — *known masses on the
wheel, φ vs force* — to Mode A, gated on *"F₀ and k measured, replacing the assumed
30.0 N"*. This matters because the assumed 30.0 N preload is upstream of the drop
table, the force ceiling and the stop-washer count. What deferring Mode B actually
costs: the bounce mode, the sprung/unsprung split, active shoulder damping, and the
φ_peak-vs-drop-height curve that sets `A_MAX` in the hard-stop CBF.

---

## 2. `RIG_Stand` — the requirement

### 2.1 The interface, and why it is fixed

The stand's outboard face **is** the motor's front mount face at **y = 42.0**. This
is not a choice — design record §1.1 fixes it: the GIM6010-8 is tapped 8 × M3 on the
Ø74 PCD from *both* ends, and bolting to the rear face was rejected because
`GAUGE_Shoulder_Motor_Interface.stl` models only the front 9.5 mm of the motor, and
the brief requires every interface to be gated on that coupon.

```
stand outboard face = motor front mount face   y = 42.00
+ Chassis_Shoulder_Plate_L 5.0                 y = 47.00
wheel centre plane (half-track)                y = 84.00
                                               --------
Mode A overhang                                  42.00 mm   (67 % of Mode B's 63.00)
```

⚠ **Anything you put between the stand and y = 42.0 — a washer, a spacer, a printed
pad, a shim — grows the overhang and scales all four moments in §2.2 linearly.**
This is §4 check 6.

**The structural joint is `Chassis_Shoulder_Plate_L`'s five existing frame-bolt
holes**, at (X, Z) = **(−60, −18), (−60, 48), (−60, 62), (30, 48), (30, 62)** on a
**120 × 120 × 5** panel spanning X −72…48, Z −48…72, with a Ø48 central bore and a
Ø64/Ø67 cable-cavity lip standing to y = 51. Those five are what the panel uses to
carry the leg on the *real robot*, so using them makes the rig reproduce the robot's
own load path — that is the whole point, and it is why you must not add a hole to
the panel.

Two patterns on the panel you must **not** use:

- **8 × Ø3.4 on the Ø74 PCD** — that is the motor's own pattern, already occupied by
  the motor's housing screws.
- **4 × Ø4.5 on the Ø88 PCD** — the removable clock-spring cover's M3 insert
  receivers. They are driven from the accessible outboard face and are not
  stand attachment points. Leave them clear of stand geometry.

Constants already in `rig_lib.py` to reuse rather than retype:
`PANEL_FRAME_BOLTS`, `PANEL_Y0`/`PANEL_Y1` (42.0/47.0), `PANEL_X0`…`PANEL_Z1`,
`MOTOR_R` (40.0), `HALF_TRACK` (84.0),
`WHEEL_R` (55.0), `Z_WHEEL_AXIS` (−154.269), `Z_FLOOR` (−209.269).

> **[CORRECTED 2026-09-14]** `INSERT_M3_D = 4.5`, insert length is 5.0,
> and the stand hole depth is 6.0 mm. Fusion verified five receivers spanning
> y = 36…42 with a 6 mm printed floor. Nominal Ø4.0 failed in the owner's ABS
> result; the owner selected the dedicated ladder's largest, unmarked-end Ø4.5
> station. The promoted source and bed-ready stand export passed Fusion MCP
> verification.

### 2.2 The load set — yaw dominates by 4×

From `rig_calc.mode_a_stand()`. **The design load is the actuator's own reaction
torque, not impact** — brief §4.1 wrote that about the MGN12H and it applies verbatim
to a printed stand.

| Load | Value | Axis | Note |
|---|---:|---|---|
| Pitch — spring-limited wheel force 54.80 N × 42.00 mm | **2.30 N·m** | X | trivial |
| Roll — its ground reaction 71.3 N × 42.00 mm | **2.99 N·m** | Z | trivial |
| **Yaw — shoulder stall about the motor axis** | **11.00 N·m** | **Y** | **DOMINANT** |
| Vector sum, yaw + roll | **11.40 N·m** | — | **design against this** |
| Yaw at proof screen | **25.00 N·m** | Y | screening load |

**The stand's job is torsional, not vertical.** The static hanging load is
irrelevant by comparison: 0.8401 kg of leg (8.24 N), or 1.2281 kg with a 388 g
GIM6010-8 and 1.3401 kg with a 500 g one — about 3 % of the yaw it is sized by. This
is also why **conflict C4 (motor mass 388/150 vs 500/250 g) decides nothing
structural in Mode A**; weigh the motors anyway for the two-leg budget.

The **54.80 N** force ceiling is a property of the *spring*, not the fixture — the
knee spring is the softest element in the load path, so nothing downstream can see
more than it transmits, however hard the leg is loaded. Deleting the slide does not
raise it. (51.44 N at +25°, 16.13 N at equilibrium.)

### 2.3 The five-bolt joint carries all of it

From `rig_calc.mode_a_bolt_group()`. In Mode A there is no MGN12H block, no register
and no dowel sharing the load — five M3 in shear are the entire joint.

| | |
|---|---|
| Group centroid | **X −24.00, Z +40.40** — 47.0 mm off the motor axis, *not* on it |
| Σr² about the centroid | 14 179 mm² |
| Worst radius | 68.60 mm |
| Worst screw shear at 11.00 N·m | **53.2 N** → 2.22 MPa bearing on an 8 mm wall |
| Worst screw shear at 25.00 N·m | **121.0 N** → 5.04 MPa bearing on an 8 mm wall |

Against PA-CF's ~84 MPa XY, **bearing is not the limit**. The limit is the M3
heat-set insert's grip in printed nylon. ⚠ **That magnitude is unverified.**
Published pull-out figures for M3 brass heat-sets scatter very widely with material
and hole geometry — roughly 200–400 N in PLA at the low end, and CNC Kitchen
measured up to ~1.4 kN at the small-hole end of its range — and **none of those
tests are PA-CF at our geometry, and our load case is shear rather than axial
pull-out.** So treat the insert as the weak element and design *for* it rather than
quoting a number at it: a 5.0 mm-deep coupon-controlled pocket, real material
around the boss, and a depth-stopped installation tip.

Two consequences that should shape the geometry:

- **Spread the five landings as far as the panel allows.** Shear goes as 1/Σr², so a
  compact boss cluster is the one way to make this joint the failure point.
- **Do not model the joint as five bolts on a circle about the shoulder.** The
  centroid is 47.0 mm off-axis, so the yaw torque also tries to rotate the panel
  about that offset point.

### 2.4 It must be clamped, not weighted

This is the requirement most likely to be quietly skipped, so it gets its own
section. Hold-down needed to resist 11.00 N·m by dead weight alone:

| Base half-width | Weight needed |
|---:|---:|
| 100 mm | 110.0 N = **11.2 kg** |
| 150 mm | 73.3 N = 7.5 kg |
| 200 mm | 55.0 N = 5.6 kg |
| 250 mm | 44.0 N = 4.5 kg |
| 300 mm | 36.7 N = **3.7 kg** |

**A printed stand is ~0.3 kg.** No practical base width holds 11 N·m by dead weight.
The stand **must be clamped or bolted to the bench**, and the CAD must *show* the
clamp or bench-bolt path rather than assume it — that is new §4 check 7.

Design in explicit clamp landings: flat, parallel, accessible from above and below,
at least two per side, sized for a common F-clamp or bar-clamp jaw. For reference, an
Irwin Quick-Grip medium-duty one-handed bar clamp is rated up to **300 lbf** of
sustained force and the heavy-duty version up to **600 lbf**, so clamp *capacity* is
not the constraint — the constraint is whether your geometry gives the jaw something
square to bite on, and whether the printed landing crushes under it. Add bench clamps
to the purchase list; the Mode A build needs **more** of them than Mode B did.

### 2.5 Height, and the floor

The stand must hold the shoulder axis **≥ 221.31 mm** above the floor plate. That is
the ride height at the −8° extension stop, which is where a free leg actually rests:

| Knee angle | Shoulder axis above floor |
|---|---:|
| −8°, the extension stop | **221.31 mm** |
| 0°, the modelled pose | 209.27 mm |
| +25°, the design point | 163.19 mm |
| +27°, against the stop | 159.13 mm |

`RIG_Floor_Plate` (260 × 60 × 6) stays: it is what the wheel rests on, and it is
what stops the leg falling when the shoulder is de-energised. A 6 mm aluminium plate
is the better part if one is available — the wheel rolls ~77 mm during a shoulder
sweep, and if it scrubs, every force reading is corrupt.

Related figure, for step 6: **the preload floor is 8.25 N.** Below that a free leg
just rests on the −8° stop, so the threshold to watch during loading is φ leaving
the stop, not a force reading.

### 2.6 Print orientation

Per `beni_rig_no_machining.md` §1: **5 walls · 40 % gyroid · 0.15 mm layers ·
top-of-range temp · minimal cooling · dried filament.** PA-CF is 84–102 MPa in XY
and only 26–50 MPa in Z, so **orientation is the strength lever and infill is not.**

For the stand specifically: **the dominant load is torsion, not bending.** Keep the
11.00 N·m yaw path in the print plane; do not let it try to peel layers apart. State
the chosen orientation in the builder's docstring and in `rig_stl/README.md` §9,
which already has a placeholder entry for this part.

`beni_rig_no_machining.md` §3 also flags the measurement consequence: **the stand is
now the softest element in the load path**, and its deflection shows up as shoulder
*angle* error, not knee error — a different and more insidious artifact than the old
2020 column's bending. Stiffness here is measurement quality.

---

## 3. The Mode A part set

Five families, of which four already exist:

| Part | Status |
|---|---|
| **`RIG_Stand`** | **TO DESIGN.** No builder exists. |
| `RIG_Torque_Arm` | Exists — `build_rig_torque_arm()`. 200 mm lever on the hub's 6 × M4 Ø44 PCD, bearing on a 5 kg kitchen scale. Highest-value cheap part in the rig: published bench tests of this actuator found 4.8 and 9.4 N·m against an 11 N·m rating, and the jump needs 5.9 N·m = **3.01 kgf at 200 mm**. Re-run check 5 against the *stand*. |
| `RIG_Floor_Plate` | Exists — `build_rig_floor()`. Unchanged. |
| `RIG_Cable_Post_A` / `_B` | Post A was revised on 2026-09-05: it sits outside the cover, shares the upper two Ø88 holes with M3 × 12, and has an open Ø8 eye beyond the cover edge. See the [current audit](evidence/assembly/2026-09-05_access_fix/). Post B remains deferred with the deleted Mode-B column; the separate rear Mode A anchor serves the fixed harness. |
| `RIG_Knee_Stop_Plate_L` | Exists — `build_rig_knee_stop_plate()`. Still required: it carries the **−8° extension stop**, which a free leg rests on in every unloaded pose. |

**Deferred with Mode B — do not build, do not delete the builders:**
`build_rig_base`, `build_rig_column`, `build_rig_braces`, `build_rig_rail`,
`build_rig_blocks`, `build_rig_carriage`, `build_rig_index_post`,
`build_rig_index_bar`, `build_rig_mode_pin`, `build_rig_bumpers`,
`build_rig_ballast`, `build_rig_ballast_pot`, and the `check3_mode_b_travel()` /
`slide_to()` harness.

**Also deferred:** the **+27° washer-column stop** inside the spring cartridge.
Steps 1–9 never approach +27°, so Mode A never needs it — but it is **mandatory
before any drop**, and its shim is meant to be set *after* step 6 from the measured
spring, where one 1.0 mm washer moves the stop by 1.83°.

Reused unchanged, all robot parts and all unaffected by the Mode A cut:
`Proximal_Link_L`, `Wheel_Rim_L`, `Wheel_Tyre_L` (TPU 95A), `Knee_Encoder_Bracket_L`
(ABS), `Chassis_Shoulder_Plate_L`, the knee bearings, the cartridge and the spring.
Reused **modified**: `Distal_Link_L` — its Ø16 sleeve bore is now Ø10 (design record
§4), and `rig_stl/reroute/Distal_Link_L.stl` supersedes the `print_stl/` copy.

When you add the builder, also add `'RIG_Stand': 'PACF'` to `RIG_PART_CLASS` in
`rig_lib.py`, or its mass will not be counted.

---

## 4. Checks before you release CAD

Brief §4.4, Mode A set: six checks become four, plus two replacements and one new.

| # | Check | Status |
|---|---|---|
| 1 | Knee sweep −8° → +27° at nominal shoulder reproduces guide §4: **φ = +25° → 46.1 mm vertical, 24.0 mm fore-aft.** | **Unchanged** — `check1_knee_sweep()`. A mismatch means your model is wrong, not the table. |
| 2 | Shoulder sweep ±120°; the service loop must not foul the stand or the wheel. | **Unchanged in intent** — `check2_shoulder_sweep()`. Rail, column and carriage leave the exclusion list; the stand joins it. |
| 3 | Wheel clears the floor plate at **every knee angle −8° → +27°** with the stand at its designed height. | **Replaced.** Was "through the whole Mode B travel". Now a knee-sweep check, and trivial in Mode A because the wheel is *on* the floor and the stand does not move. |
| 4 | Mass properties. | **Replaced.** `slide_mass()` / `sprung_split()` are Mode B. Do the §2.2 Mode A load report instead — `rig_calc.mode_a_stand()`. |
| 5 | Torque arm cannot hit the stand at any angle you intend to load. | **Re-run.** It passed against the column with Y bands disjoint by 38.5 mm; **the stand's Y bands are different.** Arm max radius is 200.4 mm against 209.3 mm to the floor. |
| 6 | Verify the **42.00 mm** Mode A overhang. | **Replaced.** Was "re-verify the 63 mm stack-up". Assert the stand's outboard face lands exactly on y = 42.0. |
| **7** | **Prove the hold-down.** | **NEW, Mode A only.** 11.00 N·m of yaw cannot be resisted by dead weight. The CAD must show the clamp or bench-bolt path. |

Update `checks_44()` accordingly — do not leave it calling `check3_mode_b_travel()`
and `check6_stackup()`, whose assert is hard-coded to 63.0, in a Mode A build.

Also carry forward, from §6.1 of the design record: `RIG_Torque_Arm ↔
Proximal_Link_L` is an **intentional** clash — the arm *replaces* the proximal link
on the hub's 6 × M4 Ø44 PCD, and step 2 runs with the leg off. It and
`RIG_Scale_Pedestal` are `STEP2_FIXTURES` and are excluded from the sweeps. With the
pedestal fitted, keep the shoulder within **−120…+25°**.

---

## 5. Deliverables

1. Fusion assembly, **Mode A only**, reused parts in place, checks 1/2/3/5/6 plus
   the new hold-down check verified.
2. `build_rig_stand()` in `rig_lib.py`, with its orientation and reasoning in the
   docstring, and `RIG_Stand` registered in `RIG_PART_CLASS`.
3. STLs for `RIG_Stand`, `RIG_Torque_Arm`, `RIG_Floor_Plate`, `RIG_Cable_Post_A/B`,
   `RIG_Knee_Stop_Plate_L` and the five re-routed formerly-machined parts, with
   print orientation stated per part. **No carriage, no ballast pot, no index bar.**
4. A **Mode A load report** — the numbers in §2.2/§2.3 confirmed against the built
   assembly, not against this document.
5. **A snapshot of the verified rig assembly.** `Beni_Prototype1` has two entries in
   `snapshots/`; `Beni_SingleLegRig` has none, despite being the active build and
   despite §6 documenting a reproducible way to corrupt it. This is the
   highest-value missing artifact in the project — do not skip it.
6. The design record §2.3 **dowel-pin recommendation survives intact**:
   `Shoulder_Output_Hub_L` needs its three Ø4 × 10 hardened dowel pins. The
   printed register alone sees 63 MPa at the 25 N·m proof load against PA-CF's
   ~40–50 MPa shear. **The pins are not optional, but machining is prohibited:**
   structural release now waits for an as-printed PA-CF press-fit coupon; revise
   the printed retention geometry if no coupon bore works.

---

## 6. ⚠ Traps that produce *passing* wrong answers

All five are from design record §6.2, recorded because each one silently produced a
passing result that was wrong. Trap 1 is the one that will cost you a day.

### 6.1 Deleting *any* occurrence displaces both motor STEP references

**Reproducible in `Beni_SingleLegRig`** — it fired twice on the same delete. Removing
one stray M3 screw re-resolved the two external STEP references: `REF_GIM6010-8` grew
from Y 5…49 to **Y 5…75**, and the wheel motor moved **140 mm**, inventing clashes
that had nothing to do with the design.

Two dead ends already tried, so do not repeat them:

- **`occurrence.isSuppressed = True` is not a fix.** The property is not readable on
  this API build, so the assignment lands silently on the Python wrapper and changes
  nothing in the model. It *looks* like it worked.
- **You cannot simply ban the operation.** `beni_lib.build_fasteners()` deletes its
  own origin master occurrences the same way — it is house style.

**What works:** capture `transform2.asArray()` for both `REF_*` occurrences **and
every child occurrence in their trees** (7 transforms), do the delete, then write the
transforms back and assert the bounding boxes. Undo also recovers it cleanly if you
catch it immediately.

**After any structural edit, assert both boxes:**

```
REF_GIM6010-8    must read  Y  5.00 … 49.00
REF_GIM4305-10   must read  Y 61.50 … 94.50
```

### 6.2 The other four

2. **`beni_lib.interference()` reports unresolvable names.** It falls back to
   `entity.name`, which for any body built without renaming is `"Body1"`. Every rig
   clash came back as `Body1 ↔ Body2`, a filter on `'RIG_'` matched nothing, and the
   first four builds reported **zero interference when there were 49 pairs** —
   including an 11 313 mm³ brace-through-post collision. **Use
   `rig_lib.real_clashes()`**, which resolves through `assemblyContext` then
   `parentComponent`.
3. **Fusion's occurrence bounding box inflates under rotation.** It is the
   axis-aligned box of the *untransformed* box, so at φ = +25° the Ø110 tyre reports
   as **146.2 mm** tall (110 × (cos 25 + sin 25)). Any clearance read off `bbox`
   min/max for a rotated part is overstated by up to a third. **The box *centre*
   transforms exactly** — that is why `wheel_bottom()` takes centre − 55.
4. **`Sketch.saveAsDXF` after `projectCutEdges` mirrored the hole pattern.** It
   wrote the outline at (+X, −Z) and the holes at (−X, −Z), 183 mm apart. No longer
   affects a deliverable — there are no laser parts — but it means Fusion's DXF
   export cannot be trusted without an independent area check.
5. **The spring cartridge's internal length is 9.0 mm shorter than its own dimension
   chain implies.** Deriving it instead of measuring it would have put the knee's
   hard stop at +10°. **Measure, don't derive.**

### 6.3 Two more from the conventions list

- **Chirality.** Only left-hand (`_L`) parts are modelled and exported; mirror in the
  slicer. Fusion reports a mirrored occurrence under its *source* occurrence's `name`
  while the component carries the `(Mirror)` suffix — **trust the clash volume's
  bounding box, not the names.**
- **`Beni_Prototype1` is the master.** The rig is a Save-As copy. Do not edit the
  master casually, and do not propagate a rig-only change into it.

---

## 7. Where the rest of it lives

| What | Where |
|---|---|
| Every Mode A number, recomputable | `rig_calc.py` → `mode_a_stand()`, `mode_a_bolt_group()` |
| The brief, amended for Mode A | `fusion_brief_single_leg_rig.md` — §3 part table, §4.1 loads, §4.4 checks, §6 test steps, §7 deliverables |
| As-built rig record | `beni_single_leg_rig_design_record.md` — §1.1 front-face decision, §2.2 panel interface, §2.3 stack-up and moments, §6.2 traps, §9 purchase list |
| Print settings and the compliance warning | `beni_rig_no_machining.md` §1, §3 |
| What to print and in what orientation | `rig_stl/README.md` |
| The manufacturing rule | `MANUFACTURING_CONSTRAINTS.md` |
| Electronics for the Mode A rig (~$25) | `electronics/07_bom.md` Wave 0 |
| Bring-up gates | `electronics/06_logging_and_bringup.md` Stages 0–2 |
| Working rules for this repo | `CLAUDE.md` |

Reproduce the current state:

```python
import sys; sys.path.insert(0, '/Users/neilchulani/Robots/Biped')
import rig_lib
rig_lib.checks_44()          # eight Mode A checks, including receivers
rig_lib.real_clashes()
```

```
python3 -c "import rig_calc; rig_calc.mode_a_stand(); rig_calc.mode_a_bolt_group()"
```

---

## 8. The honest summary

The Mode A cut trades one deferred measurement set — bounce mode, sprung/unsprung
split, shoulder damping, and the φ_peak curve that sets `A_MAX` — for eight fewer
`RIG_*` parts and ~$60 less linear motion, and it keeps the spring characterisation
that everything downstream is computed from.

What it does **not** do is de-risk the drop question. Both the energy method and the
spring-rate method say a 100 mm drop bottoms the knee out; the passive limit is
**45 mm** planning / 46.3 mm at the +24° gate crossing. Deferring step 10 means the
two-leg build inherits that unanswered, **alongside the clock spring**. Step 6's
measured curve at least lets you predict it honestly before committing to the robot.

⚠ And one standing discipline item, because it is easy to forget on a bench: **the
brake chopper is deferred with Mode B, so nothing may backdrive a motor.** A bench
PSU cannot sink regen — it will just let the bus rise. No hand-spinning the wheel
under power, no dropping the leg off the stand, no using the wheel motor as a brake.

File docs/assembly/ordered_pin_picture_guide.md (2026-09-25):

# Beni single-leg illustrated assembly manual

**Spring-installed motion HOLD — September 24:** the owner reports spring
bowing and sideways escape during compression after assembly. Keep motors
unplugged and do not repeat spring compression pending diagnosis. Spring-free,
supported inspection may continue. [Physical failure record](../../evidence/assembly/2026-09-24_spring_escape/).
The spring-installation and hand-test steps below are held.

[Download the printable 23-page PDF](../../output/pdf/beni_single_leg_assembly_manual.pdf).

A visual parts key and 21 numbered assembly operations, using exploded views
of the corrected September 23 Fusion v30 article. Read the pages in order. Both motors stay
unplugged; clamp the stand, keep the wheel clear and hand-contain the distal side.

**Reprint the PINREV2 shoulder hub and both links.** Their root-dowel and
clevis-link holes are Ø4.30; the distal knee receiver is restored to Ø10.30.
Keep the current stop plate and other released prints, subject to the
[all-15-part audit](../../evidence/assembly/2026-09-23_mechanical_reprint_audit/);
the stand and plate in hand are owner-confirmed Ø4.5 prints. The two M4
cotter washers shown in steps 16 and 18 are not in hand: fit the cotters
directly for this unpowered test and inspect both cotter faces afterwards
([deviation record](../../evidence/assembly/2026-09-23_owner_stand_plate_and_washers/)).
The owner now reports the new prints and assembly complete; individual fit acceptance remains unverified and spring retention has failed. The
[detailed traveller](../../first_article_stl/ordered_pin_integration/README.md#ordered-assembly)
retains the acceptance checklist; [drawing provenance](manual/README.md) records
sources and illustration limits.

## 1. BENI / Single-leg assembly

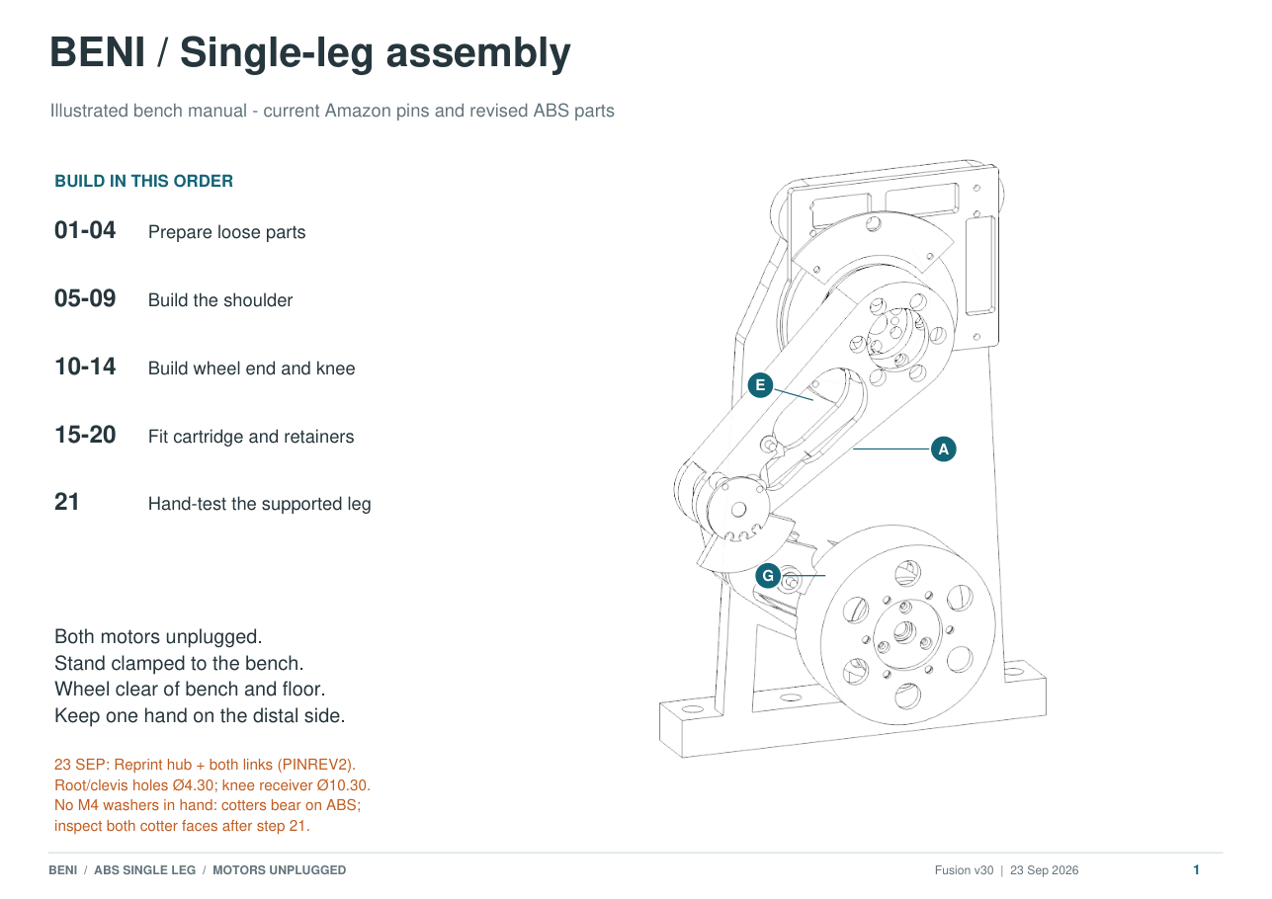
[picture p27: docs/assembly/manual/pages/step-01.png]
Page 1: BENI / Single-leg assembly


## 2. Identify your printed parts

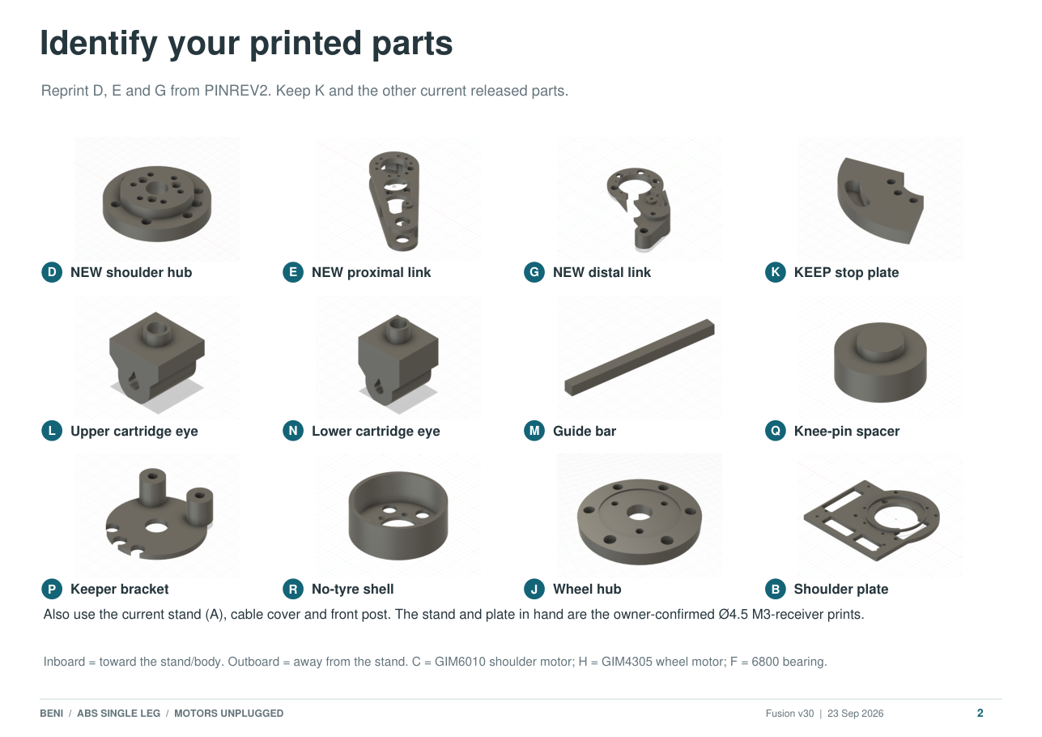
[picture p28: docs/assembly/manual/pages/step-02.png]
Page 2: Identify your printed parts


## 3. Fit the two knee bearings

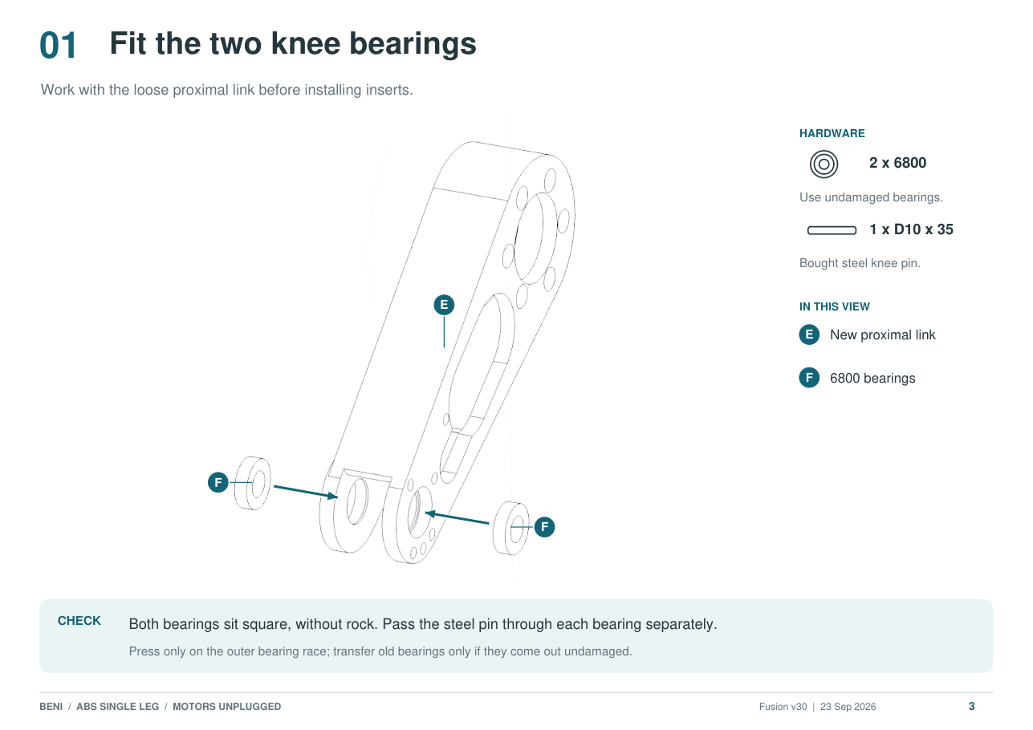
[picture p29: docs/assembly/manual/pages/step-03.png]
Page 3: Fit the two knee bearings


## 4. Insert the new hub and proximal link

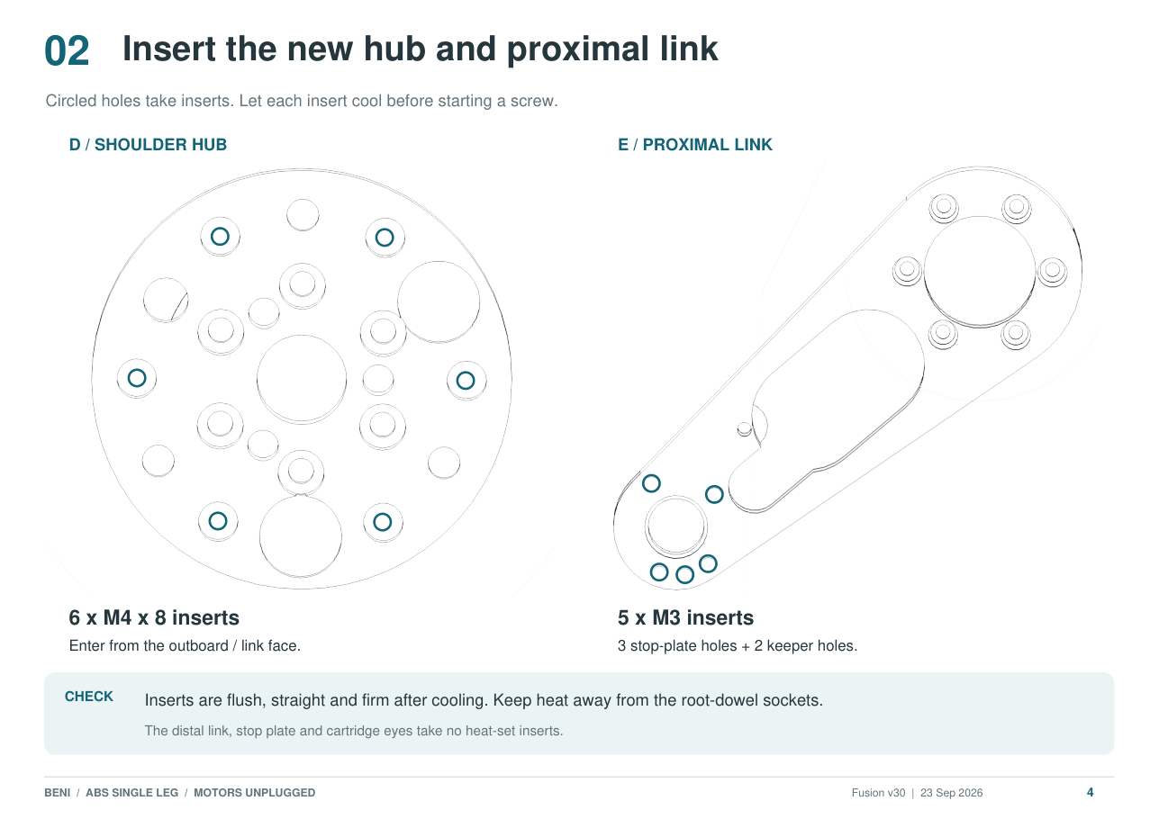
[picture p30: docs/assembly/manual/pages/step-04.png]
Page 4: Insert the new hub and proximal link


## 5. Finish the exposed insert receivers

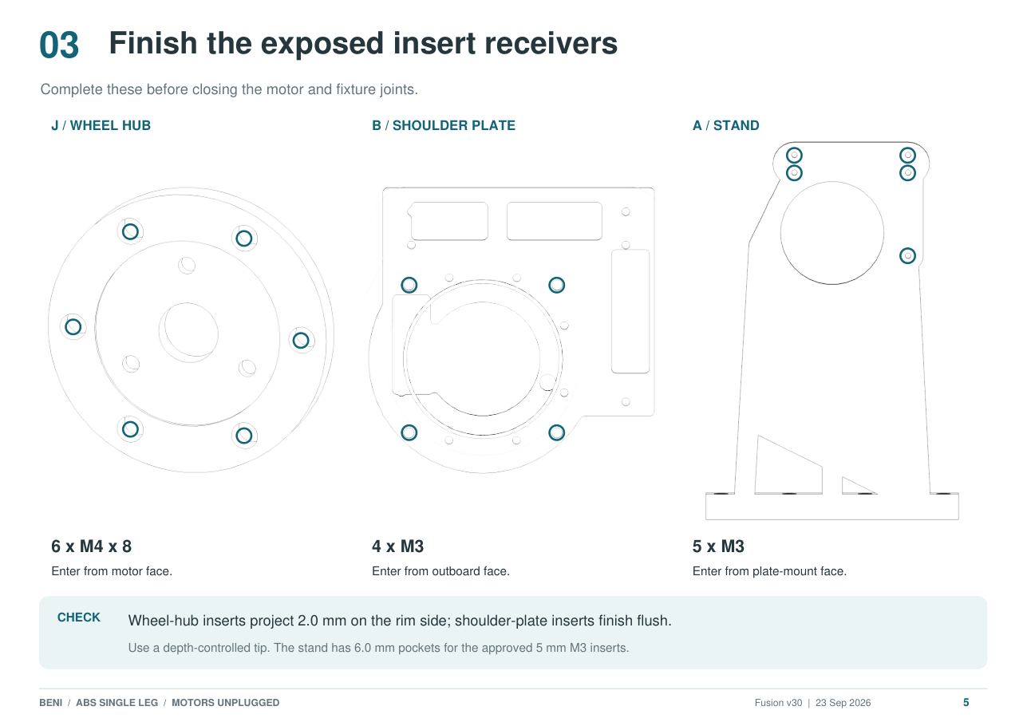
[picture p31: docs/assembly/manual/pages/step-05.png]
Page 5: Finish the exposed insert receivers


## 6. Seat the three root dowels

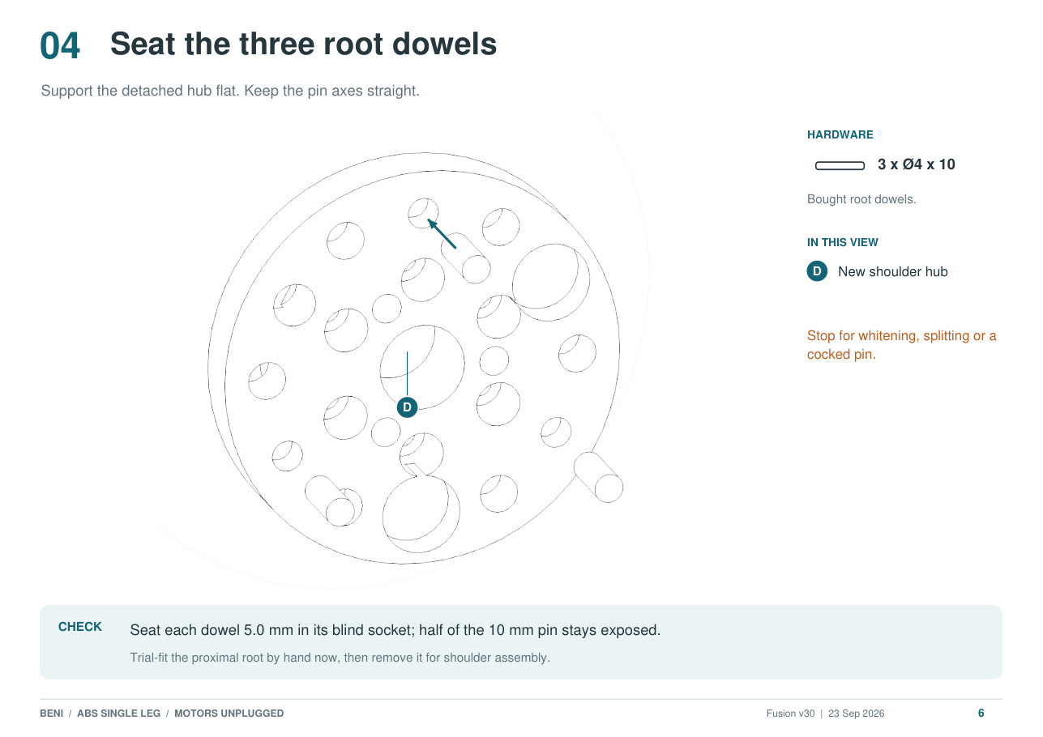
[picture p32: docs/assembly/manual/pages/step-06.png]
Page 6: Seat the three root dowels


## 7. Slide the plate over the bare rotor

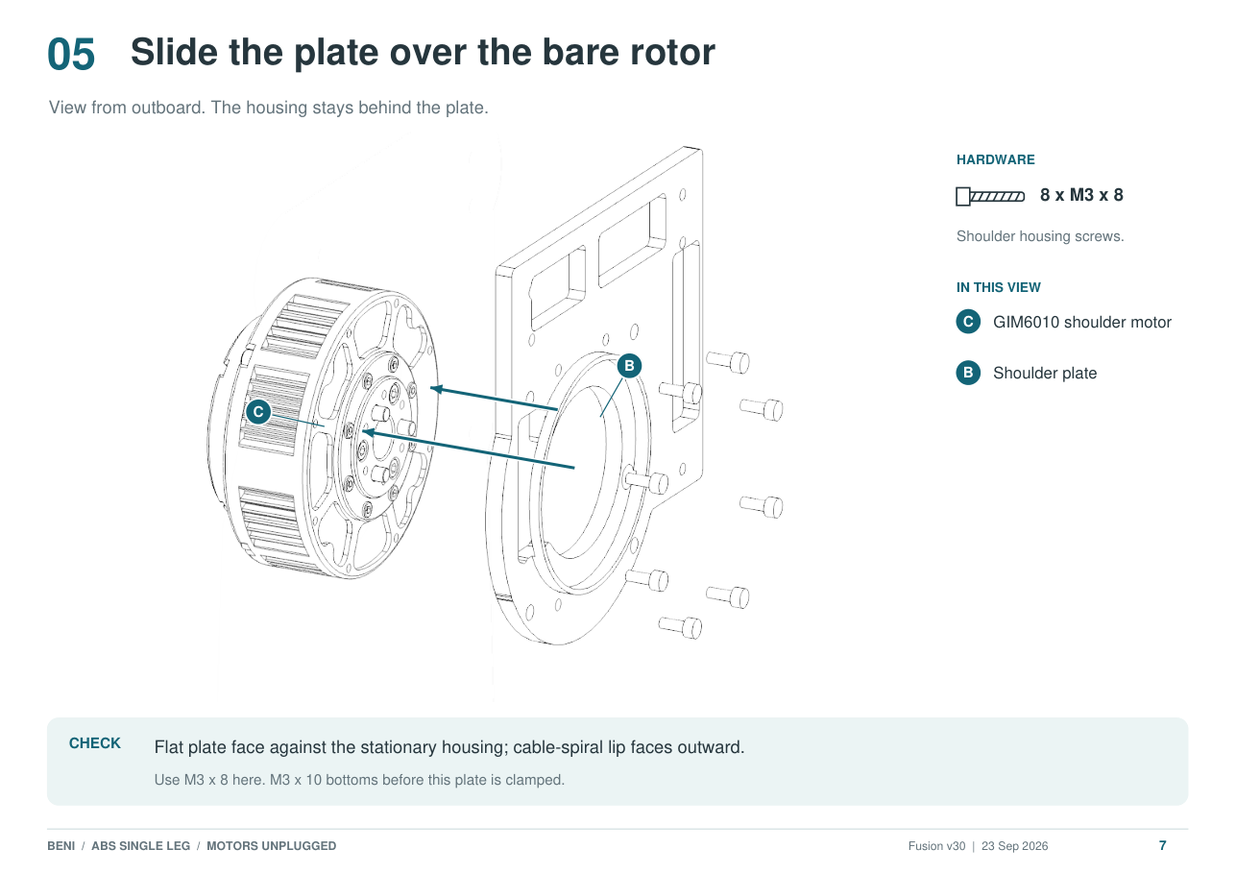
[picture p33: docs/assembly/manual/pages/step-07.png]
Page 7: Slide the plate over the bare rotor


## 8. Fasten the shoulder to the stand

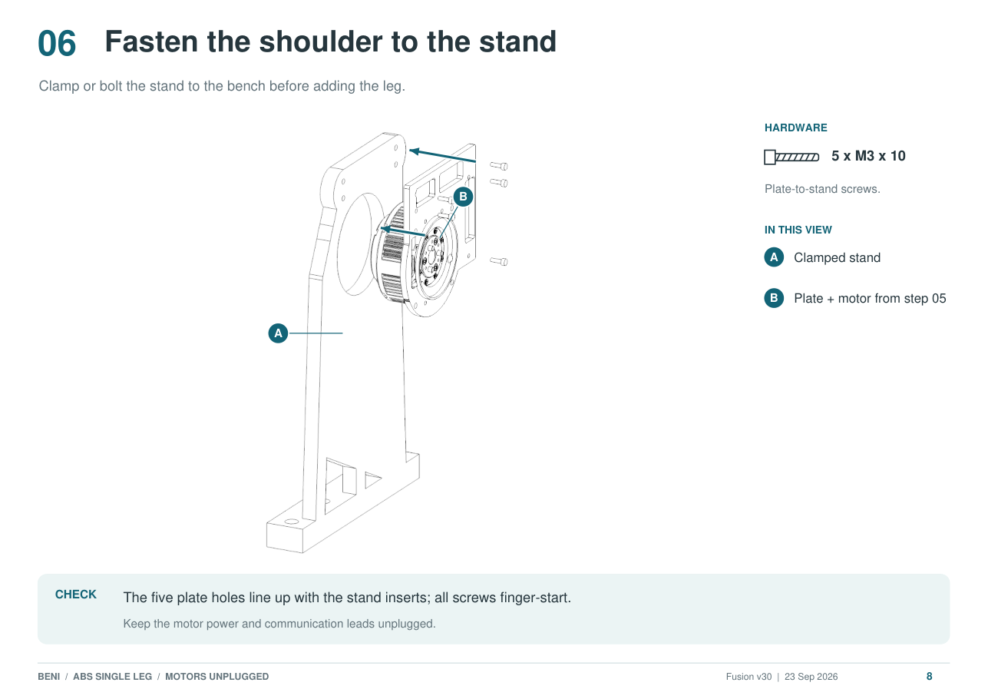
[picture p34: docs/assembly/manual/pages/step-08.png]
Page 8: Fasten the shoulder to the stand


## 9. Route the cable; fit cover and post

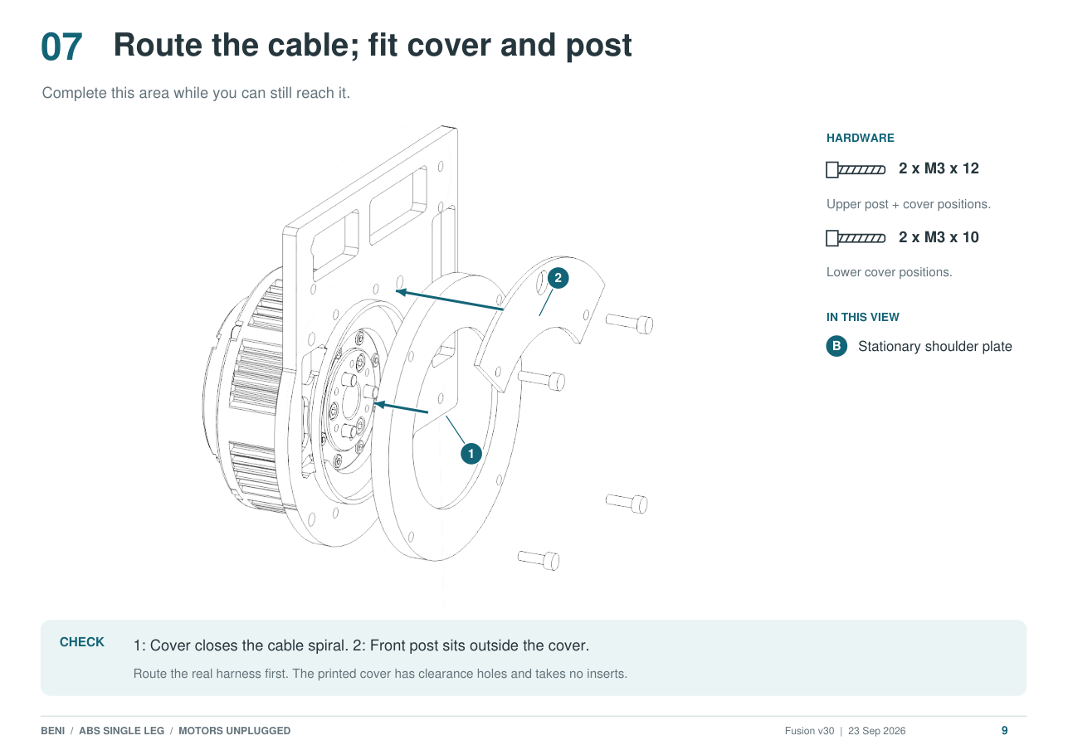
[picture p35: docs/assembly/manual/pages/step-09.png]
Page 9: Route the cable; fit cover and post


## 10. Fit the rotating shoulder hub

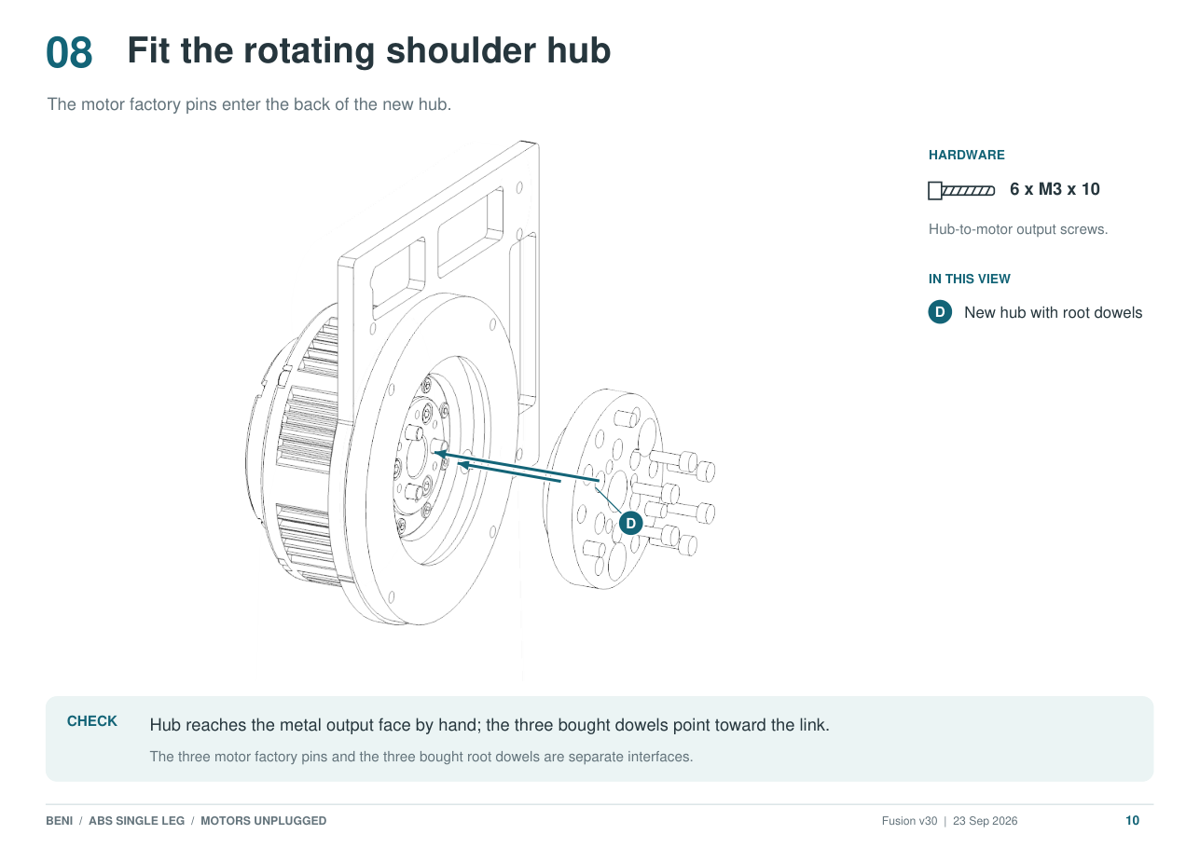
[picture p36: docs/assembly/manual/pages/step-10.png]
Page 10: Fit the rotating shoulder hub


## 11. Attach the proximal root

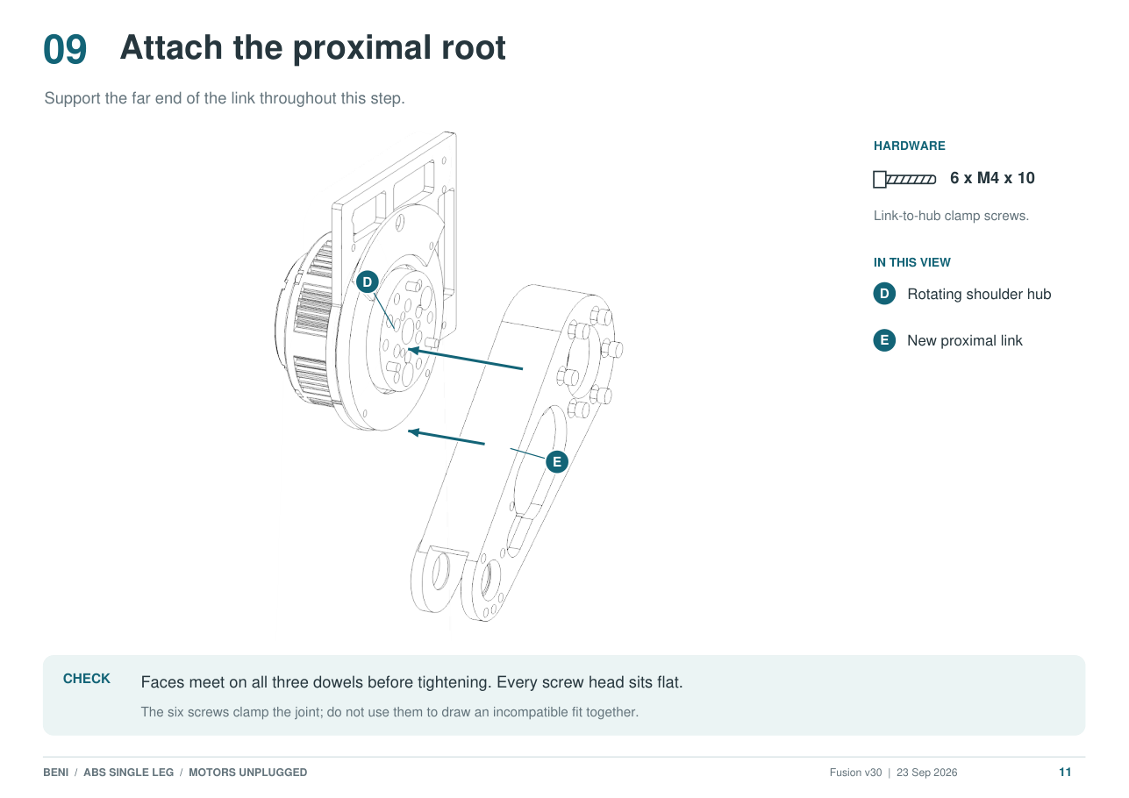
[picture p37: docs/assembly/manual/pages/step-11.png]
Page 11: Attach the proximal root


## 12. Mount the wheel motor

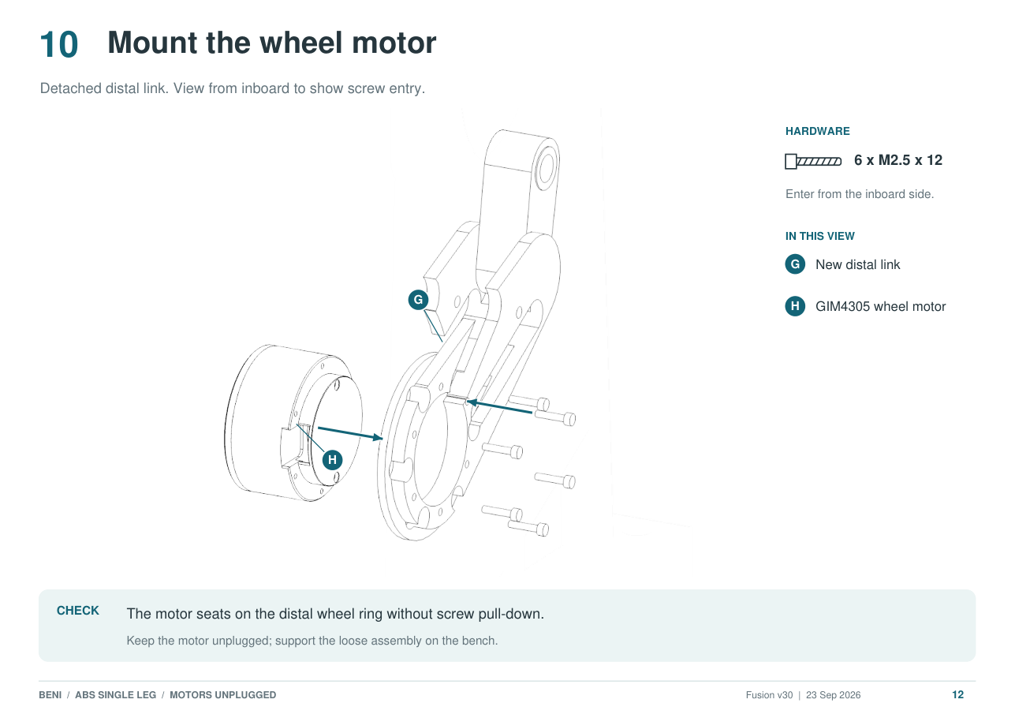
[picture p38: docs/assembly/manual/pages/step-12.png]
Page 12: Mount the wheel motor


## 13. Fit the wheel output hub

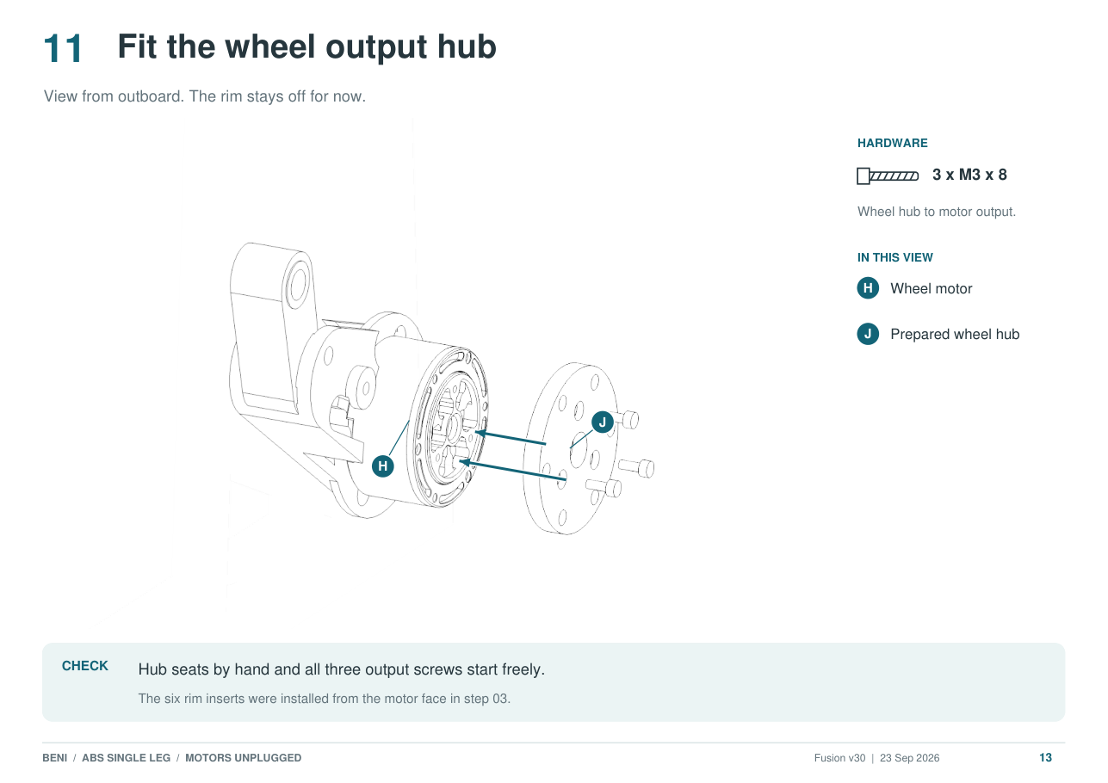
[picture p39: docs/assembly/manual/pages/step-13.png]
Page 13: Fit the wheel output hub


## 14. Bring the distal receiver into the fork

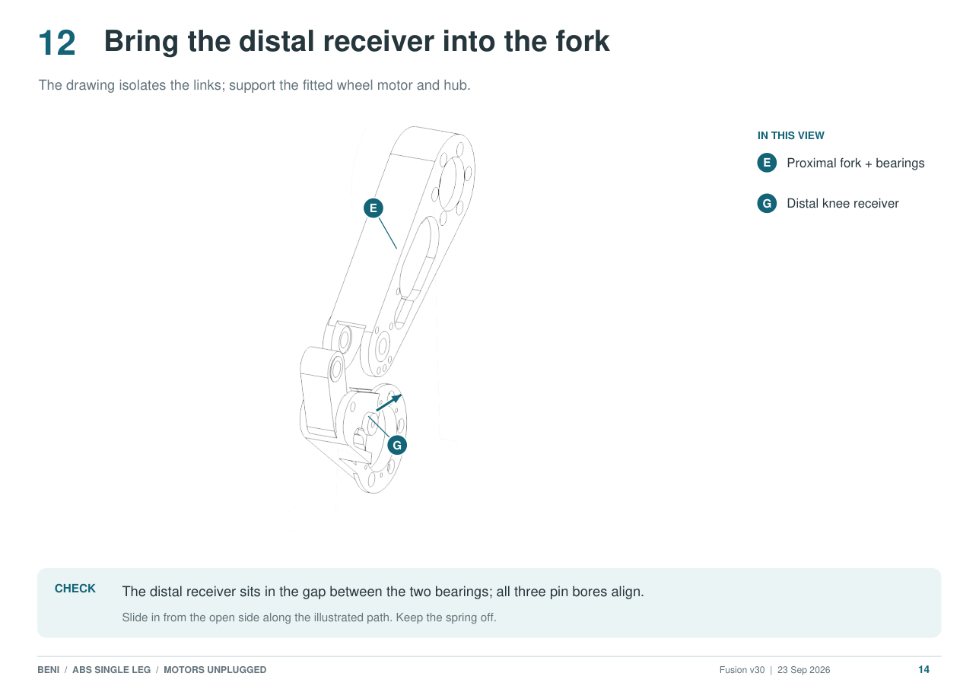
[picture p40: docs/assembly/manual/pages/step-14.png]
Page 14: Bring the distal receiver into the fork


## 15. Insert the steel knee pin

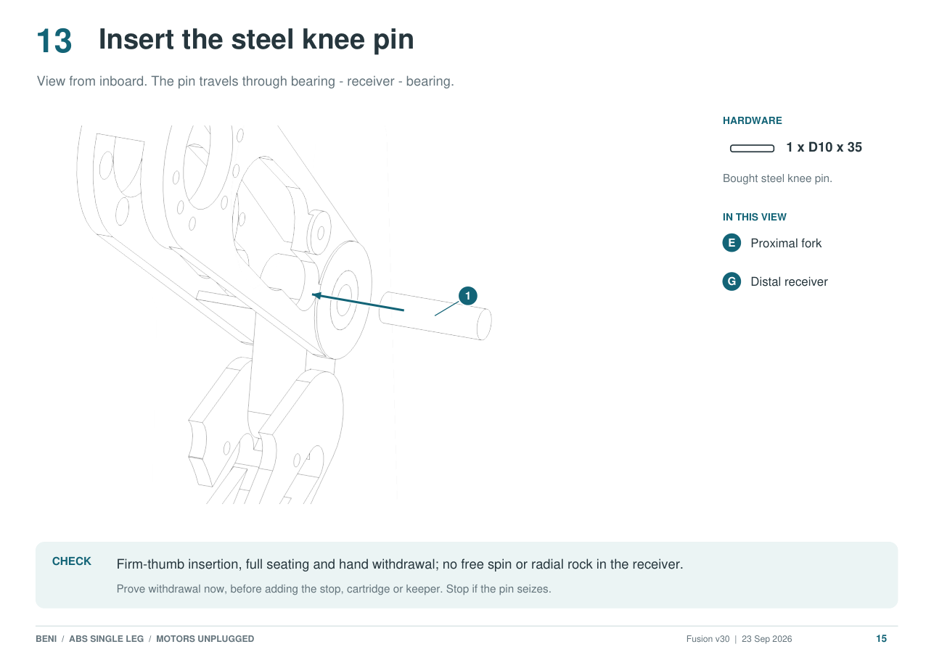
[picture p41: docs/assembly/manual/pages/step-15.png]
Page 15: Insert the steel knee pin


## 16. Capture the stop dowel

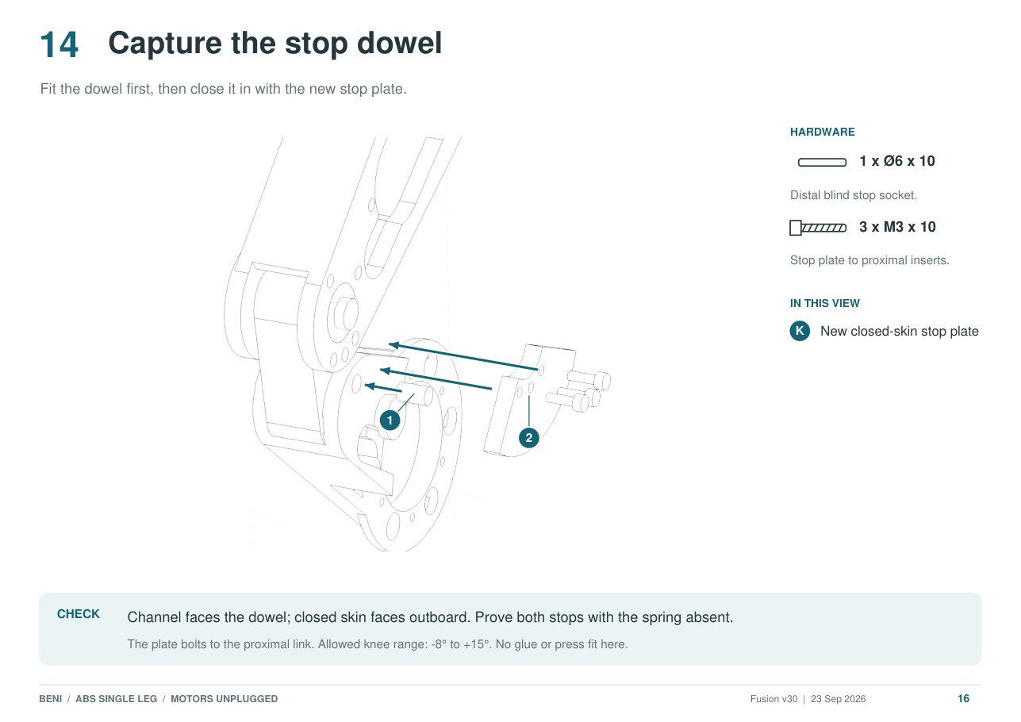
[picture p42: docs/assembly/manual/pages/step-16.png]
Page 16: Capture the stop dowel


## 17. Place the upper cartridge eye

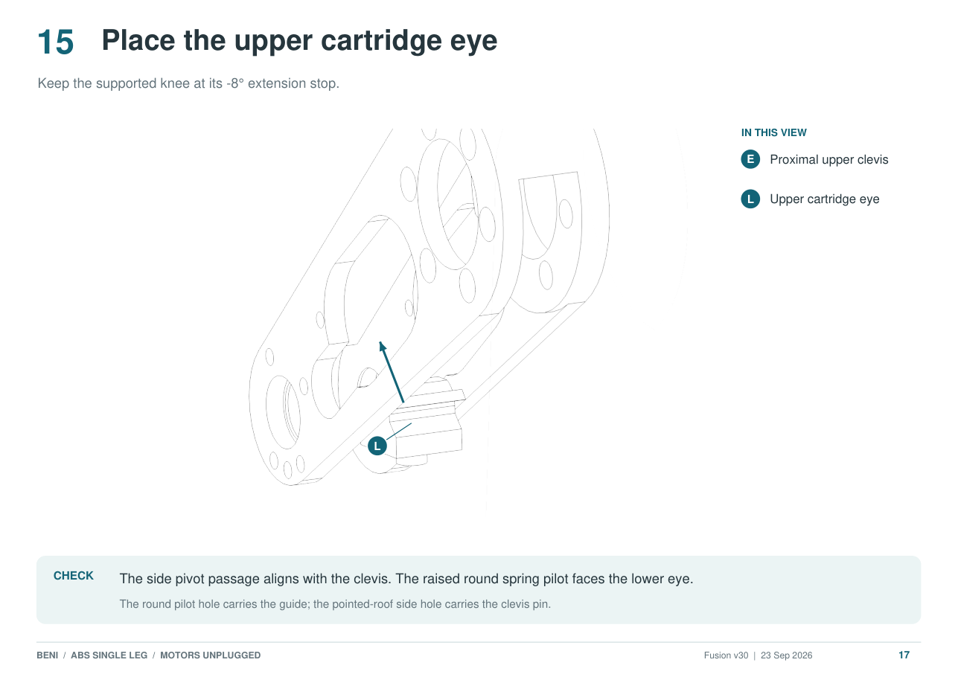
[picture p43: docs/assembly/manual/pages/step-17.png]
Page 17: Place the upper cartridge eye


## 18. Pin the upper eye

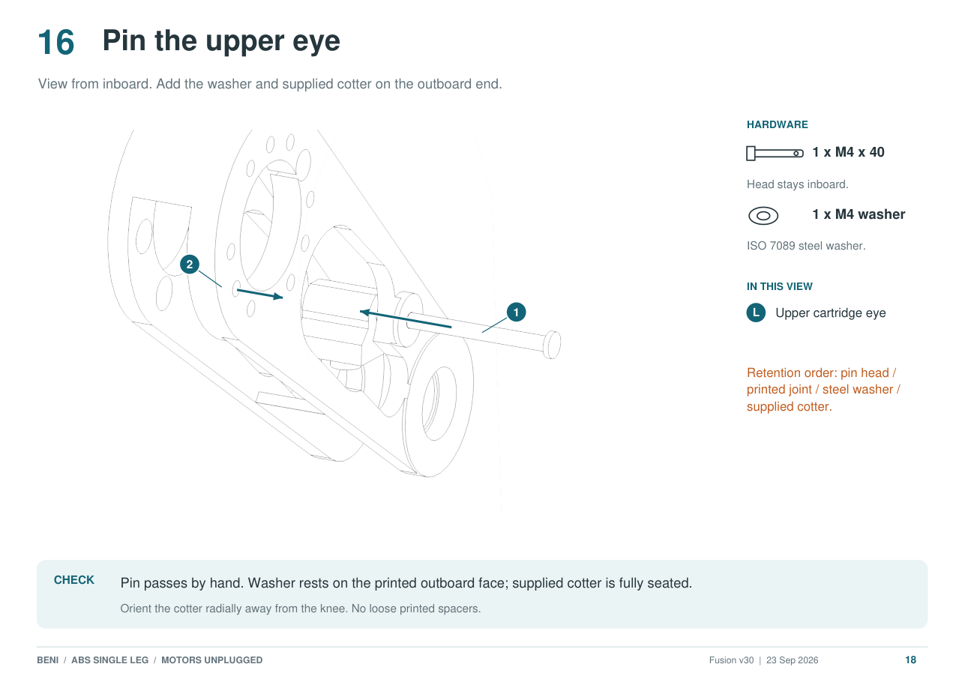
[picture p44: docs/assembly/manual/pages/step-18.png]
Page 18: Pin the upper eye


## 19. Guide first, then spring

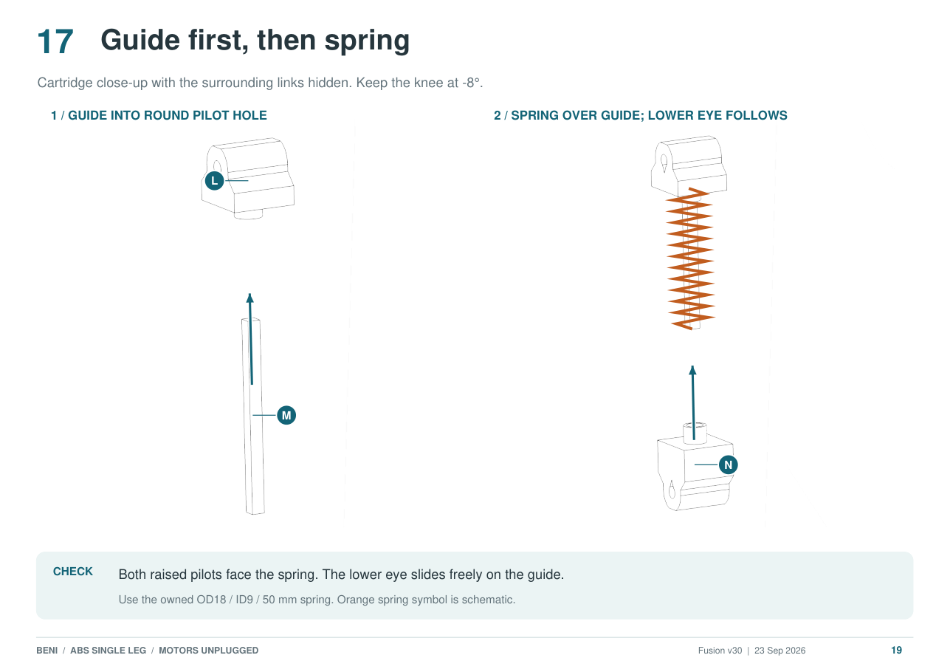
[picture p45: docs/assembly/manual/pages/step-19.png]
Page 19: Guide first, then spring


## 20. Pin the lower cartridge eye

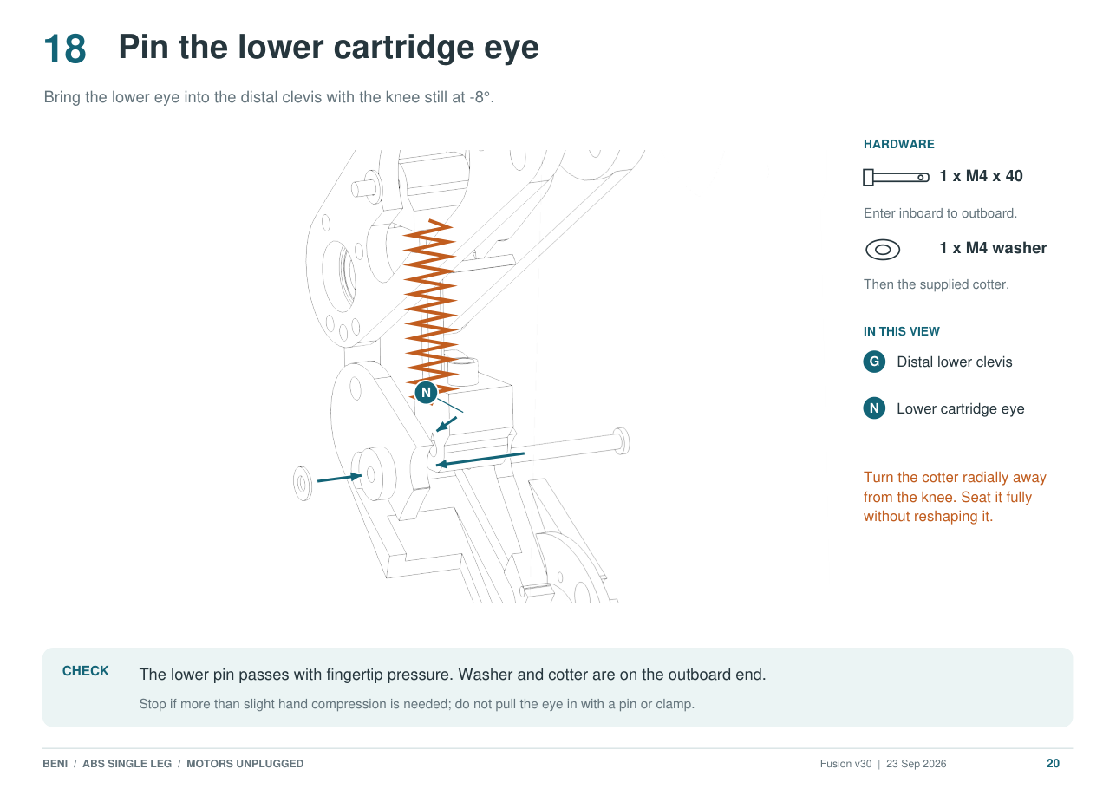
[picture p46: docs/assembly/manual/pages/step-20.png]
Page 20: Pin the lower cartridge eye


## 21. Fit the outboard knee-pin keeper

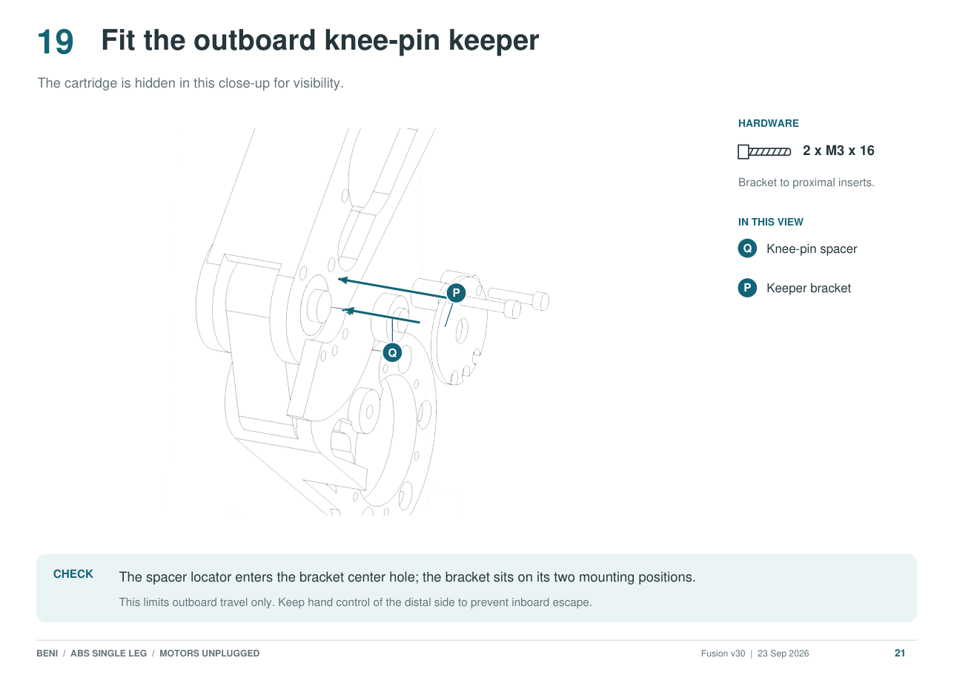
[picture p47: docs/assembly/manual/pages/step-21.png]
Page 21: Fit the outboard knee-pin keeper


## 22. Attach the no-tyre shell

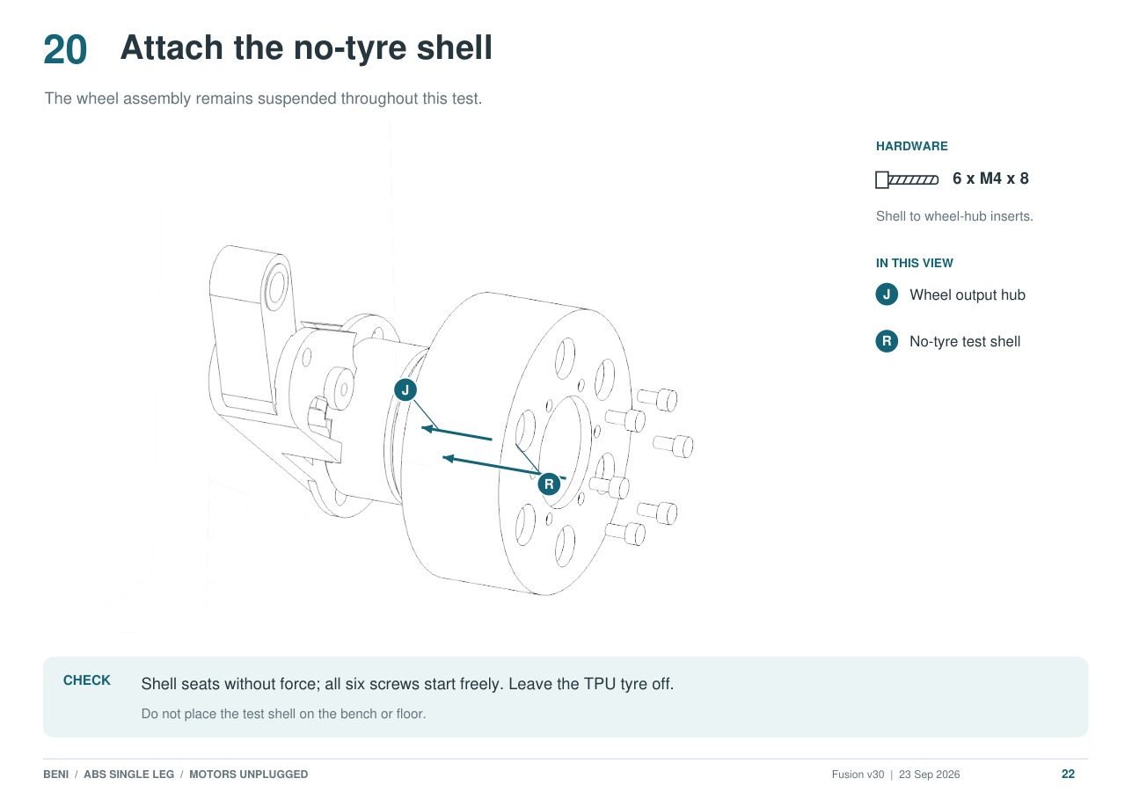
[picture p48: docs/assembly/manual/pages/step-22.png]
Page 22: Attach the no-tyre shell


## 23. Check motion by hand

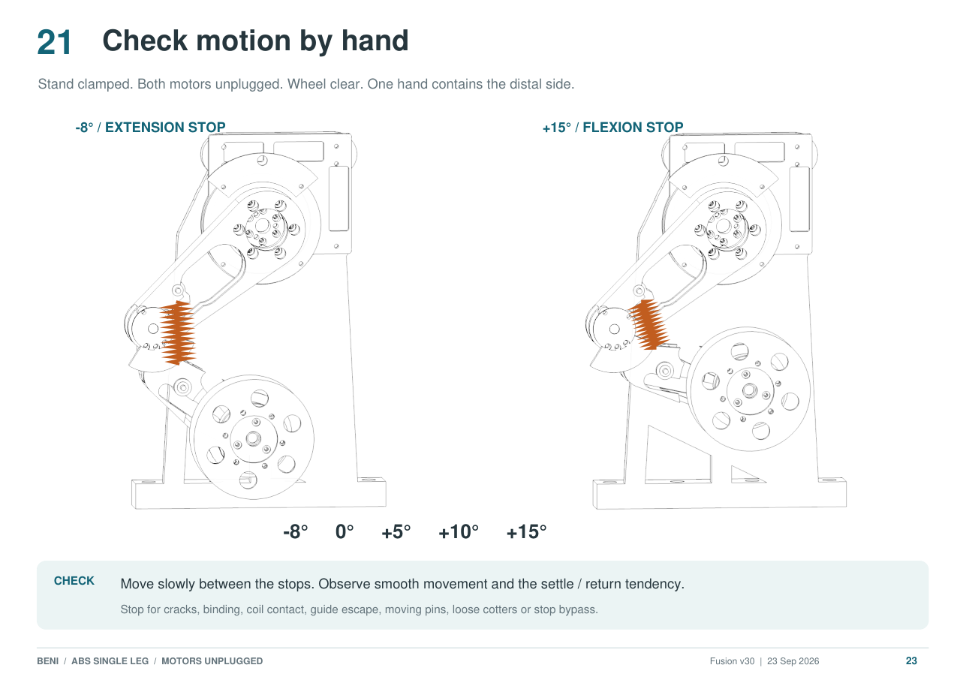
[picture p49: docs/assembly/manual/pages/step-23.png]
Page 23: Check motion by hand


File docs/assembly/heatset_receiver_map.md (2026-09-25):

# Heat-set insert map — active ABS single leg

**Five parts receive inserts: 14 × M3 (5 mm long) and 12 × M4 (8 mm long).**
Use the approved Voron-style M3 and owned Kadriick M4 × 8 inserts.
The owner reports the three PINREV2 replacement parts printed. Of those three,
only the **shoulder hub and proximal link** receive inserts; the distal link
receives none. Skip inserts already fitted in accepted retained parts.

Each picture below faces the **insert-entry side**. **Numbered rings mark the
insert holes**; unmarked holes do not receive inserts. Numbers identify holes,
not an installation sequence. Click a picture to enlarge it.

| Part | Install | Entry face | Finished depth |
|---|---|---|---|
| [New shoulder hub](#shoulder-hub--6-m4) | 6 × M4 × 8 | Outboard: meets the proximal link | Flush at both ends |
| [New proximal link](#proximal-link--5-m3) | 5 × M3, 5 mm long | Outboard knee face: stop plate / keeper side | Flush |
| [Shoulder plate](#shoulder-plate--4-m3) | 4 × M3, 5 mm long | Outboard: cable-cover side | Flush at both ends |
| [Mode A stand](#mode-a-stand--5-m3) | 5 × M3, 5 mm long | Shoulder-plate mounting face | Flush; 1.0 mm remains below insert |
| [Wheel hub](#wheel-hub--6-m4) | 6 × M4 × 8 | **Motor side** | Flush on motor side; **2.0 mm projects on shell side** |

## Shoulder hub — 6 M4

Shoulder hub: six numbered outer receivers, viewed from the link side

Use the **new PINREV2 hub**. Install six M4 × 8 inserts into the numbered
Ø5.3 through holes in its outer flange, from the face that meets the proximal
link. The flange is 8.0 mm thick, so both insert ends finish flush.

The inner motor-screw holes and the three Ø4.30 root-dowel sockets take **no
inserts**. Keep the dowel sockets clear of the iron and molten plastic. Fit the
three root dowels only after the inserts have cooled. The six M4 × 10 screws
later pass through the proximal root and thread into these hub inserts.

## Proximal link — 5 M3

Proximal knee close-up: blue holes 1–2 for the keeper bracket, orange holes 3–5 for the stop plate

Use the **new PINREV2 proximal link**. Find the **small knee-bearing end**, then
turn the part to the outboard face with **five small blind pockets** around the
bearing opening. The large shoulder ring is at the opposite end of the link.

- **Blue 1–2:** two M3 inserts for the encoder bracket used as the knee-pin keeper.
- **Orange 3–5:** three M3 inserts for the knee stop plate.

All five inserts are 5 mm long and finish flush in Ø4.5 × 5.0 mm blind pockets.
The six shoulder-root screw paths take **no inserts**: their screws thread into
the shoulder hub. The stop plate and keeper bracket themselves also take none.

## Shoulder plate — 4 M3

Shoulder plate: four numbered receivers around the motor opening, viewed from the cover side

Face the side with the raised cable-routing lip around the motor opening—the
side that meets the cable cover. Install four 5 mm M3 inserts in the **four
numbered holes around that opening**, flush through the 5.0 mm plate.

The other holes are screw clearances. In particular, the plate-to-stand screws
pass through the plate and thread into the **stand's** inserts. Put **no inserts
in the cable cover or front cable post**.

## Mode A stand — 5 M3

Stand viewed from the shoulder-plate mounting face: four receivers at the top and one beside the motor opening

Face the upright surface that meets the shoulder plate, with the bench base
at the bottom. Install five 5 mm M3 inserts: **four near the top, plus the fifth
beside the motor opening**, as numbered. These Ø4.5 × 6.0 mm blind pockets leave
1.0 mm below a flush insert. The base's bench-mounting holes take no inserts.

The stand and shoulder plate in hand were confirmed as the current Ø4.5
receiver prints on September 23.

## Wheel hub — 6 M4

Wheel hub viewed from the motor face: six outer receivers; inner motor-screw holes remain clear

Install six M4 × 8 inserts in the **six outer numbered holes**, entering from
the **motor face shown**. Leave the three smaller inner motor-screw holes clear.

**This is the depth exception:** the hub is 6.0 mm thick and each insert is
8.0 mm long. Stop flush on the motor face, leaving **2.0 mm of brass projecting
from the opposite, wheel-shell face**. Those ends enter the shell's reliefs.
Do not try to make both ends flush. The no-tyre wheel shell takes no inserts.

## Parts that receive no inserts

Distal link, knee stop plate, cable cover, front cable post, upper and lower
spring eyes, guide bar, knee-pin spacer, encoder/keeper bracket and no-tyre
wheel shell.

## Before and after heating

1. Rehearse the [detached fit checks](../../first_article_stl/ordered_pin_integration/README.md#ordered-assembly)
   first, including the new link's bearing seats and screw paths. Install
   inserts with the parts detached and motors unplugged.
2. Use the selected ABS receiver sizes: Ø4.5 for M3 and Ø5.3 for M4. Do not
   install into superseded Ø4.0 M3 prints. These fit selections apply to the
   same ABS profile; PA-CF needs new coupons later.
3. Use a perpendicular, depth-controlled tip. Follow the finished depths above,
   especially the wheel-hub projection. Let the part cool without a screw fitted.
4. Reject tilted or loose inserts, or an end standing proud where flush is
   required. Start screws with fingers; never use screw torque to straighten
   an insert or draw incompatible parts together.

## Sources and drawing provenance

Dimensions and hardware follow the [canonical threaded-interface map](../../MANUFACTURING_CONSTRAINTS.md#threaded-interfaces-in-printed-parts)
and the [current ordered-pin traveller](../../first_article_stl/ordered_pin_integration/README.md).
Earlier hub installation and screw-seat passes remain historical evidence;
new-print installation and fit still require physical checks.

These diagrams reuse **unchanged Fusion MCP captures of corrected v30 / PINREV2**
from the [assembly manual](manual/README.md). The numbered rings use the
recorded receiver coordinates in [its manifest](manual/views/manifest.json),
selecting the entry-face mouth for each hole. The proximal close-up is a viewport
onto that same capture. No geometry is generated or inferred from an STL.

Rebuild the SVG documentation overlays with
`python3 docs/assembly/heatset/build_map.py`. This does not operate Fusion or
change the source captures. New CAD views must be captured through Fusion MCP.
Future chassis-frame, Mode B carriage and optional electronics receivers remain
in the [canonical deferred-interface table](../../MANUFACTURING_CONSTRAINTS.md#threaded-interfaces-in-printed-parts);
they are outside this assembly.

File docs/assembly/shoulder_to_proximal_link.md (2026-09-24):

# Picture guide — GIM6010 shoulder to proximal link

This is the visual dry-fit sequence for the **left ABS single-leg article**. It
shows where the printed proximal link goes and which motor it belongs to.

> **Use the GIM6010-8 shoulder motor. Do not try this link on the GIM4305-10
> wheel motor.** Keep the motor unplugged, fit both 6800 bearings in the new
> proximal link, and support the knee end so the printed parts do not carry it as a
> cantilever. This is a fit check, not a powered or load test.

> **Updated 2026-09-23:** use the PINREV2 hub and proximal link reprints, with
> Ø4.30 root-dowel sockets. The September 22 ordered-pin prints and the earlier
> accepted hub and link remain fit evidence only. The three bought Ø4 × 10 root dowels enter the new
> hub before this shoulder assembly. Follow the
> [current ordered-pin traveller](../../first_article_stl/ordered_pin_integration/README.md#ordered-assembly)
> for the full unpowered leg sequence.

For this unpowered ordered-pin article, follow the
[current assembly traveller](../../first_article_stl/ordered_pin_integration/README.md#ordered-assembly).
The [two-leg BOM](../../beni_prototype1_bom_and_assembly.md#b-leg-build) is
background for the later structural build.

## Parts used in this check

- GIM6010-8 shoulder motor
- `Chassis_Shoulder_Plate_L`
- the current `ABS_PINREV2_Shoulder_Output_Hub_D4p15_ROOT_D4p30` hub with
  3 × Ø4 × 10 bought root dowels
- the current `ABS_PINREV2_Proximal_Link_D19p15_ROOT_D4p30_CLEVIS_D4p30` link and
  two 6800-2RS bearings
- 8 × M3 × 8 housing screws
- 6 × M3 × 10 shoulder-output-hub screws
- 6 × owner-held Kadriick M4 × 8 heat-set inserts and
  6 × M4 × 10 proximal-link-to-hub screws

For the initial dry fit, only finger-start the screws. Do not apply final torque
or use screws to pull parts together.

## 1. Start with the output hub removed

The shoulder plate goes over the **bare output rotor** from the motor's front
side. The Ø80 motor housing stays behind the plate; it is not supposed to pass
through the plate opening.

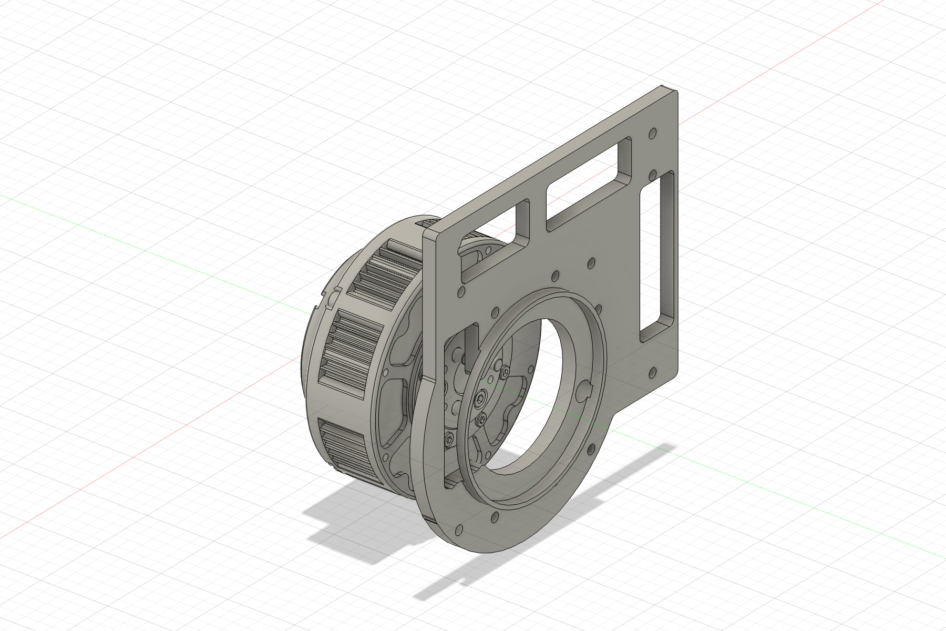
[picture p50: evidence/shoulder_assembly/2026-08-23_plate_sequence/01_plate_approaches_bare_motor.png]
Shoulder plate approaching the bare GIM6010 motor while the output hub is removed


Hold the plate with its raised cable-spiral lip facing away from the motor and
its flat panel face toward the stationary motor housing.

## 2. Seat the plate on the stationary housing

Finger-start two opposite **M3 × 8** housing screws, then verify that the other
six start freely. Do not substitute M3 × 10 screws here: they bottom before the
5 mm plate is clamped.

If you are routing the real harness, place it in the plate's cable spiral before
the output hub and proximal link cover this area.

## 3. Install the revised printed output hub second

With the detached hub supported flat, install its six M4 × 8 inserts from the
outboard/link face and seat the three bought Ø4 × 10 dowels 5.0 mm into their
selected Ø4.30 blind sockets. Reject whitening or splitting. The iron must
not touch the dowel sockets.

Align the hub with the GIM6010's three factory pins and move it straight onto
the output face. The pins must enter with light finger pressure and the hub must
reach the metal face without screw force.

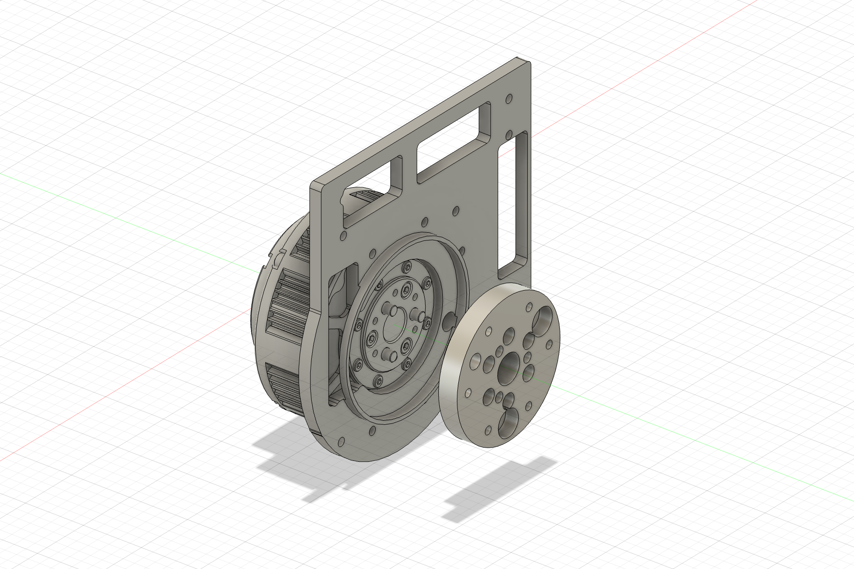
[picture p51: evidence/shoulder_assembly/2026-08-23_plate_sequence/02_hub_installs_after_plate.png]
Printed shoulder output hub approaching the GIM6010 after the shoulder plate is seated


Once seated, finger-start the six **M3 × 10** output-hub screws.

The photograph below shows the **earlier** hub-to-real-motor fit. The shoulder
plate is absent and the pictured hub has been superseded, so use it only to
identify the motor/output direction:

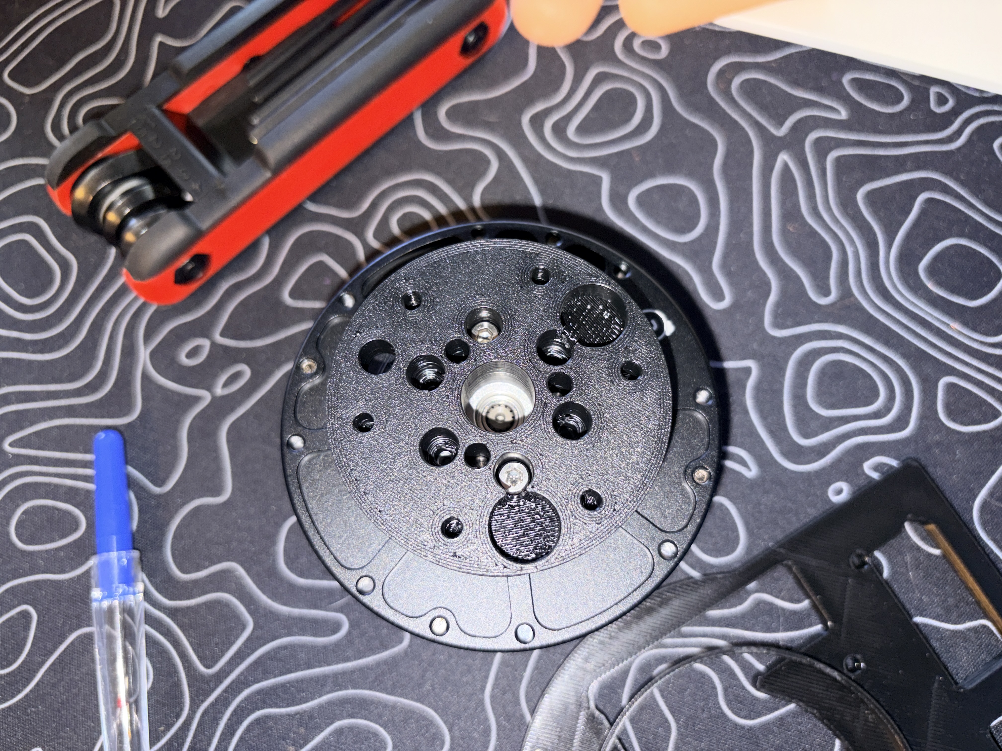
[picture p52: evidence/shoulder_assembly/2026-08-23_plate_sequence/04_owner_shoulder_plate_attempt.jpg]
Owner photograph of the printed shoulder output hub seated on the real GIM6010 output


## 4. Confirm the shoulder stack before adding the link

At this point the stationary plate is behind the printed rotating hub. Nothing
should be pinched between the hub and plate.

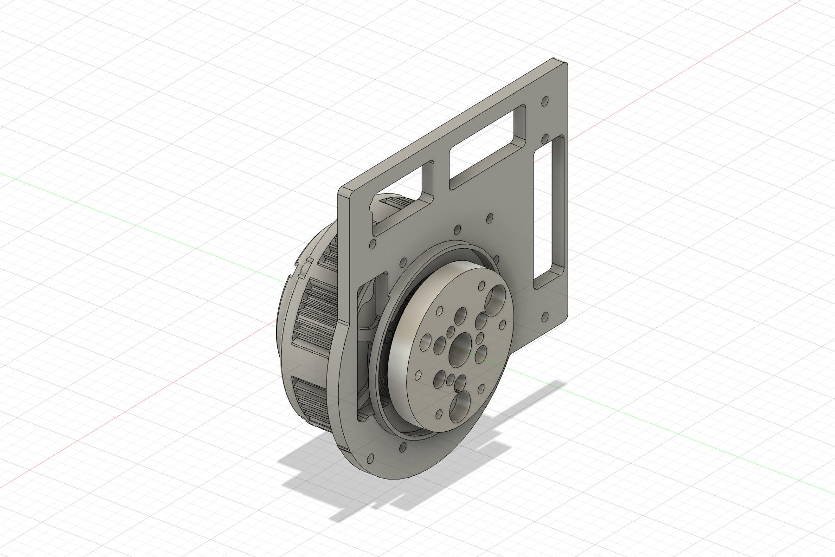
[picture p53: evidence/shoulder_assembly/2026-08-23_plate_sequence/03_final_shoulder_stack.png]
Completed GIM6010 shoulder plate and output hub stack before the proximal link is attached


## 5. Identify the proximal-link root

The **large circular end with six counterbores and the Ø34 centre access** is the
shoulder end. The forked end containing the two installed 6800 bearings points
away from the shoulder motor toward the knee.

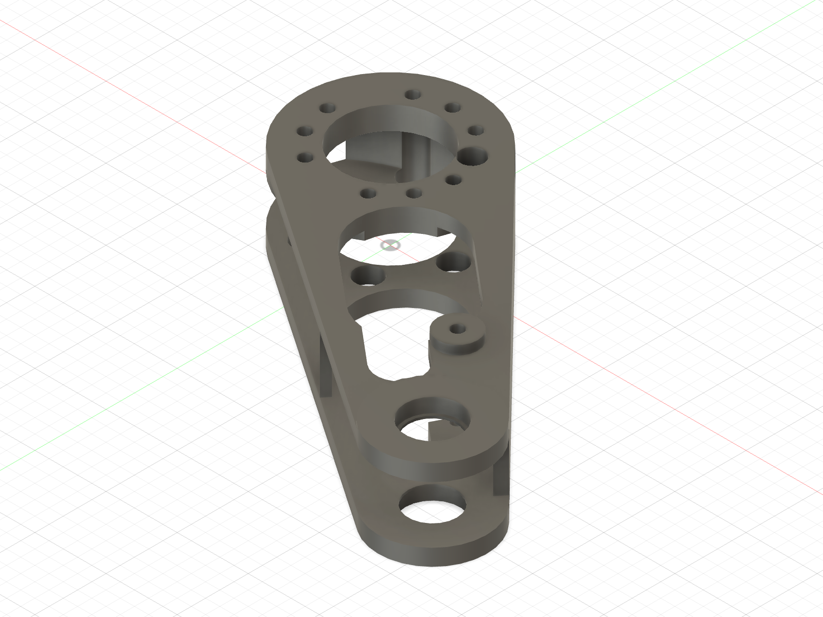
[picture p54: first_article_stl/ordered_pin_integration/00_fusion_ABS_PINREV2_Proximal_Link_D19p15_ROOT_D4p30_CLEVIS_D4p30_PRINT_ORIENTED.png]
Current ordered-pin proximal link showing the shoulder root and forked bearing end


Do not put either end of this link against the GIM4305 wheel motor. That motor
mounts to the current ordered-pin distal link, while it is still detached.

## Where the heat inserts go

The proximal link does **not** bolt into the shoulder plate. Its six M4 screws
pass through the link's root counterbores and thread into six inserts installed
from the outboard face of the **rotating shoulder hub**.

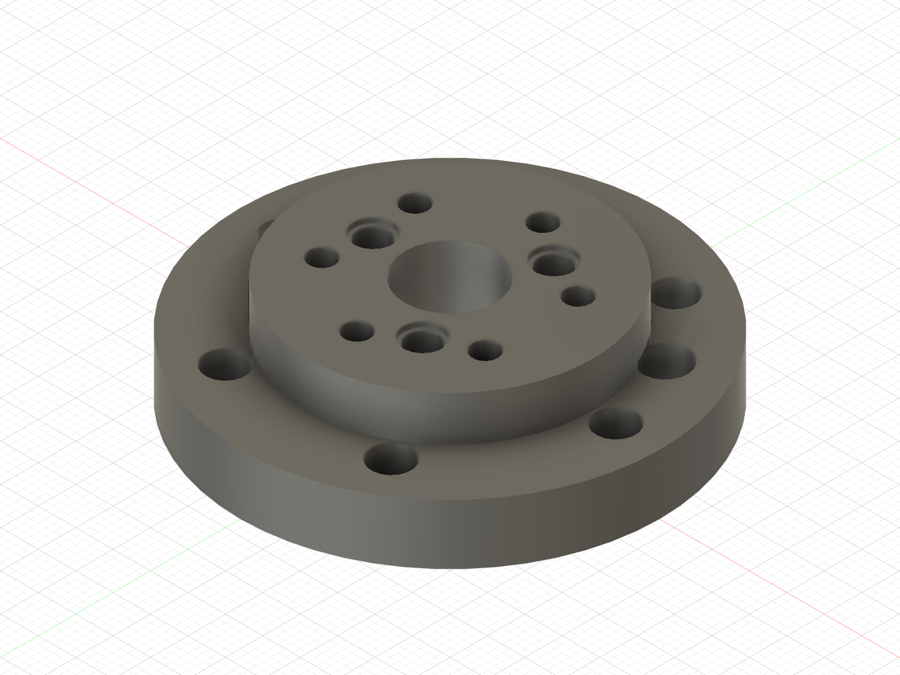
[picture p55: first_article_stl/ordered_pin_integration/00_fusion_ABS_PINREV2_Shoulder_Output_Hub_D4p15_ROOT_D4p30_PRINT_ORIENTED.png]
Current ordered-pin hub with six M4 receiver bores and three root-dowel sockets


The picture shows the current hub with Fusion-exported **Ø5.3 ABS M4 receivers**
and three Ø4.30 root-dowel sockets. Install six fresh M4 × 8 inserts in the
detached revised hub from the outboard/link face with a depth stop. Each
occupies the full 8.0 mm flange.
M4 × 10 link screws have 6.2 mm thread engagement and 1.8 mm end clearance in
the final pose. The corrected link has continuous head and driver access.

The four smaller M3 inserts in the shoulder area belong in the **stationary
shoulder plate**, only for the removable cable cover. The cover itself has four
Ø3.4 clearance holes and no inserts; its M3 × 10 screws are installed from the
accessible outboard face.

| Shoulder plate — four M3 receivers | Cable cover — four clearance holes |
|:---:|:---:|
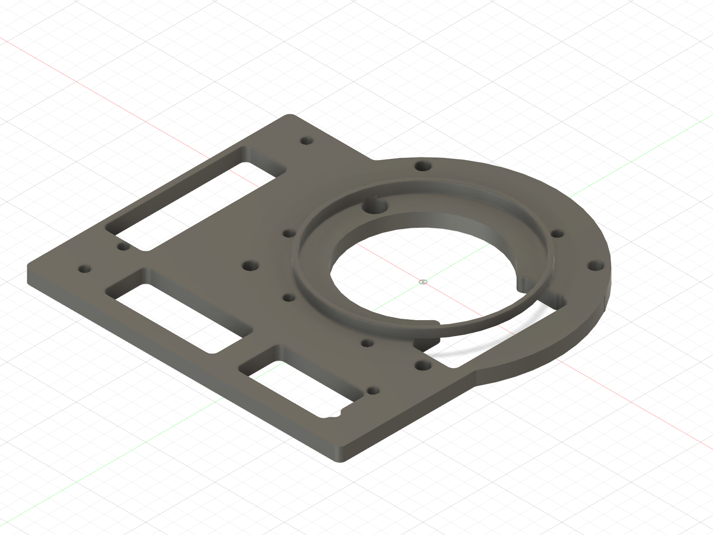
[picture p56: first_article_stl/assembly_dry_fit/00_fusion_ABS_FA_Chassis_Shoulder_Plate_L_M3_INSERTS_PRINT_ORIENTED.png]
Print-oriented shoulder plate with four M3 insert receivers around the motor opening
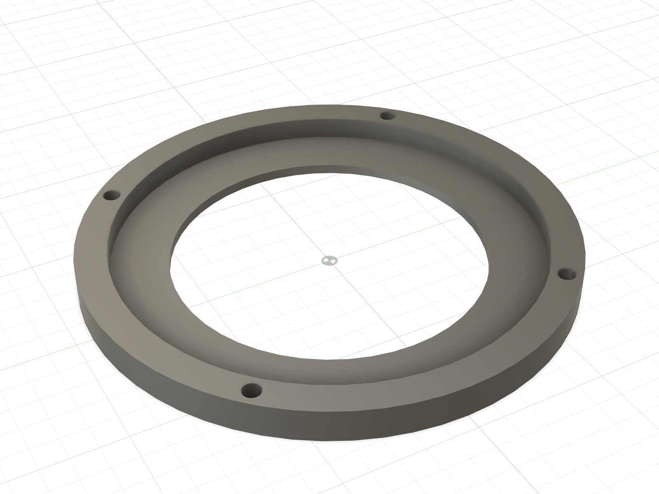
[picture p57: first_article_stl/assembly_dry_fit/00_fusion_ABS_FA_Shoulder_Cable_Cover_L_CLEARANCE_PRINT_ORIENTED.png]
Print-oriented shoulder cable cover with four clearance holes and no inserts
|  |  |

## 6. Rehearse the revised link, then attach it

Use `ABS_PINREV2_Proximal_Link_D19p15_ROOT_D4p30_CLEVIS_D4p30_PRINT_ORIENTED.stl`.
Before fitting the link, pass each of the six M4 × 10 screws through its outer
access hole. Every head must rest flat on its counterbore floor without force.
The lightening opening now stops short of the previously clipped seat.

Rehearse both bearing seats with outer-race thumb pressure. Both bearings must
sit square and have no perceptible radial rock. Reuse old bearings only if they
can be removed without damage. The current replacement has five verified Ø4.5
M3 pockets selected from the same-profile ABS ladder. Install the five M3
inserts in this new link after inspection.

Support the knee end. Move the link straight onto the three new root dowels;
its Ø4.30 × 5.2 slip sockets must allow both faces to meet by hand. Then
finger-start all six M4 × 10 screws and check each head clamps flat. Do not
use screws to draw the link into place. Remove and refit it once to confirm
the service path.

If fitting front cable post A, put it on the outside of the cover first. Its
upper two screws are **M3 × 12**, replacing the two upper cover M3 × 10;
the lower two remain ×10. The post's eye projects beyond the cover edge. Route
the tie and harness before the link, then hand-check clearance with the knee
supported. Remove the link before servicing the cover; remove cover/post before
accessing the housing screws.

[Exact Fusion audit and physical acceptance](../../evidence/assembly/2026-09-05_access_fix/).
The PINREV2 distal reprint restores the selected Ø10.30 × 20.0 steel-pin
receiver; the September 22 distal print lacks it and must not be used. The
reprint's physical knee-pin fit and supported spring-free stop check are next. Keep both motors unplugged for this rehearsal.

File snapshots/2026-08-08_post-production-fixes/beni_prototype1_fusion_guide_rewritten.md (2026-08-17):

# Beni-Like Wheeled Biped — Prototype 1 Fusion Design Guide

## 1. Mission and agent behavior

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

- Shoulder: **Steadywin GIM6010-8**
- Wheel: **Steadywin GIM4305-10**

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

### Work autonomously
Continue until the complete robot and all validation checks are finished.

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

---

# 2. Architecture to reproduce

The best-supported reconstruction of Beni is:

**body → active rotary shoulder → proximal link → passive spring-loaded cylindrical knee/elbow → distal link → driven wheel**

This serial biped morphology is intentional. Mondo previously built a parallel-leg prototype and reported that it was mechanically stiffer and more robust, but moved to the current bipedal morphology. Do **not** replace this design with an Ascento-style four-bar, active knee, or telescoping leg simply because it is easier mechanically.

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

## Knee
The knee is **passive**. There is no knee actuator.

The knee contains the compliant spring mechanism and sits between the proximal and distal leg links. The exact internal Beni spring linkage is not public; the mechanism below is the engineered Prototype 1 implementation chosen because its kinematics and force curve work.

## Wheel
The wheel motor is fixed to the distal link and independently drives the wheel.

---

# 3. Important mechanical behavior

Do not model or reason about the passive knee as if it were commanded by shoulder position.

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

Do **not** require a deep static knee fold as the normal squat mechanism.

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

### Jump
The important observed Beni behavior is:

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

### Landing
The passive knee handles the first impact/compliance and stores/returns energy. The active shoulder must also be allowed to **yield and provide active damping** rather than mechanically locking during landing.

This follows the same general lesson demonstrated by Ascento: passive leg compliance is useful, but active hip/shoulder control can act as a virtual spring-damper during landing.

---

# 4. Frozen Prototype 1 kinematics

Use these as global Fusion parameters unless the motor STEP geometry proves a direct physical conflict.

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

**distal angle = -50° - φ**

Do not reverse this convention accidentally.

### Fusion geometry checkpoints

With the shoulder fixed at nominal:

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

At nominal, shoulder-to-wheel vertical distance is approximately **154.3 mm**.

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

---

# 5. Passive knee spring mechanism

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

## Anchor geometry

Let K be the knee axis.

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

### Cartridge geometry checkpoints

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

Extension-to-+25° cartridge stroke: **15.47 mm**.

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

---

# 6. Spring target

Prototype target:

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

Expected per-leg vertical ground capacity:

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

### Starting physical spring envelope
Model a replaceable spring approximately:

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

A228 music wire is acceptable for early prototypes.

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

Treat the spring specification as **replaceable/tunable**, not a permanently trapped part.

---

# 7. Knee construction

Preferred starting hardware:

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

---

# 8. Shoulder module

Use the supplied GIM6010-8 STEP as the dimensional source of truth.

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

Exact variant/driver must be verified separately.

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

### 360° wiring
Prototype 1 requires a full ~370° physical joint range, not unlimited spinning.

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

Do not add a slip ring unless unlimited repeated multi-turn rotation becomes an actual requirement.

---

# 9. Wheel module

Use the supplied GIM4305-10 STEP as the dimensional source of truth.

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

---

# 10. Materials and FDM rules

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

---

# 11. Structural load cases

Use these as screening cases, not as claims of exact landing physics.

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

---

# 12. Landing energy design

A 3.5 kg robot dropped 100 mm reaches approximately **1.4 m/s** before contact.

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

Design intent:

**passive knee compliance + active shoulder yielding/damping + progressive final bumper**

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

Keep provisions modular so a small physical damper can be added later if needed.

---

# 13. Serial Fusion workflow

Use real Fusion components, not a monolithic body.

Run these phases **serially**:

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

Assemble and sweep -185° to +185° before proceeding.

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

### Phase 5 — Distal link
Create as a separate component with knee and wheel-motor interfaces.

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

Check the eye-to-eye checkpoint table at -8°, 0°, +10°, +20°, +25°.

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

### Phase 8 — Wheel module
Motor mount, hub, wheel envelope, fasteners and wiring.

### Phase 9 — Complete one-leg assembly
Only now assemble the full leg.

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

Do not duplicate the leg until this passes.

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

Fix every failure and rerun the affected checks.

---

# 14. Required motion/configuration checks

Create named Fusion positions/configurations for:

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

---

# 15. Acceptance checklist

Do not declare completion until all are true:

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

---

# 16. Deliverables

The Fusion project must contain:

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

---

# 17. Do not change these without demonstrating a failure

For Prototype 1, preserve:

- serial Beni-like morphology;
- active 360° shoulder;
- passive spring knee;
- L1 = L2 = 120 mm;
- ±50° nominal link geometry;
- -8° to +27° passive knee range;
- Ru 36 mm / Rl 54 mm / 110° nominal spring-anchor geometry;
- ~10.45 N/mm replaceable main spring target;
- late-travel progressive bumper;
- active shoulder damping as part of landing strategy;
- PA-CF for primary printed load paths;
- no active telescoping leg;
- no Ascento-style parallel linkage;
- no active knee;
- no slip ring unless unlimited multi-turn shoulder rotation is actually required.

---

# Research basis / known uncertainty

The following were checked when this guide was rewritten:

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

**Known uncertainty:** no public teardown or engineering drawing found exposes Beni's exact internal spring-knee linkage. The active-shoulder + serial passive cylindrical-knee + driven-wheel morphology is evidence-backed. The specific two-pivot guided compression-spring cartridge in this guide is an engineered reconstruction selected because its kinematics, progressive wheel rate, package size, serviceability, and first-prototype manufacturability have been checked.

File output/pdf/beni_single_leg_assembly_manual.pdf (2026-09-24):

# BENI / Single-leg assembly

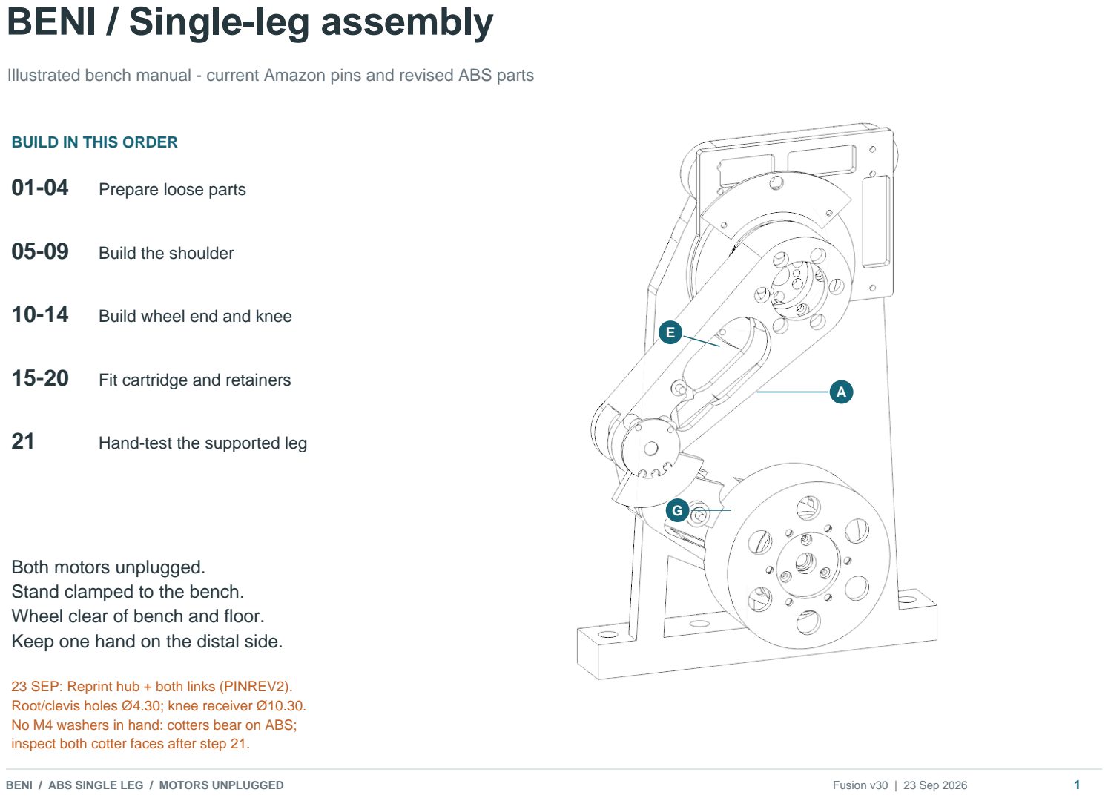
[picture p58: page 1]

Illustrated bench manual - current Amazon pins and revised ABS parts

E

G

A

BUILD IN THIS ORDER

01-04 Prepare loose parts

05-09 Build the shoulder

10-14 Build wheel end and knee

15-20 Fit cartridge and retainers

### 21 Hand-test the supported leg

Both motors unplugged.
Stand clamped to the bench. Wheel clear of bench and floor. Keep one hand on the distal side.

23 SEP: Reprint hub + both links (PINREV2). Root/clevis holes Ø4.30; knee receiver Ø10.30.
No M4 washers in hand: cotters bear on ABS;
inspect both cotter faces after step 21.
BENI / ABS SINGLE LEG / MOTORS UNPLUGGED | Fusion v30 | 23 Sep 2026 | 1

# Identify your printed parts

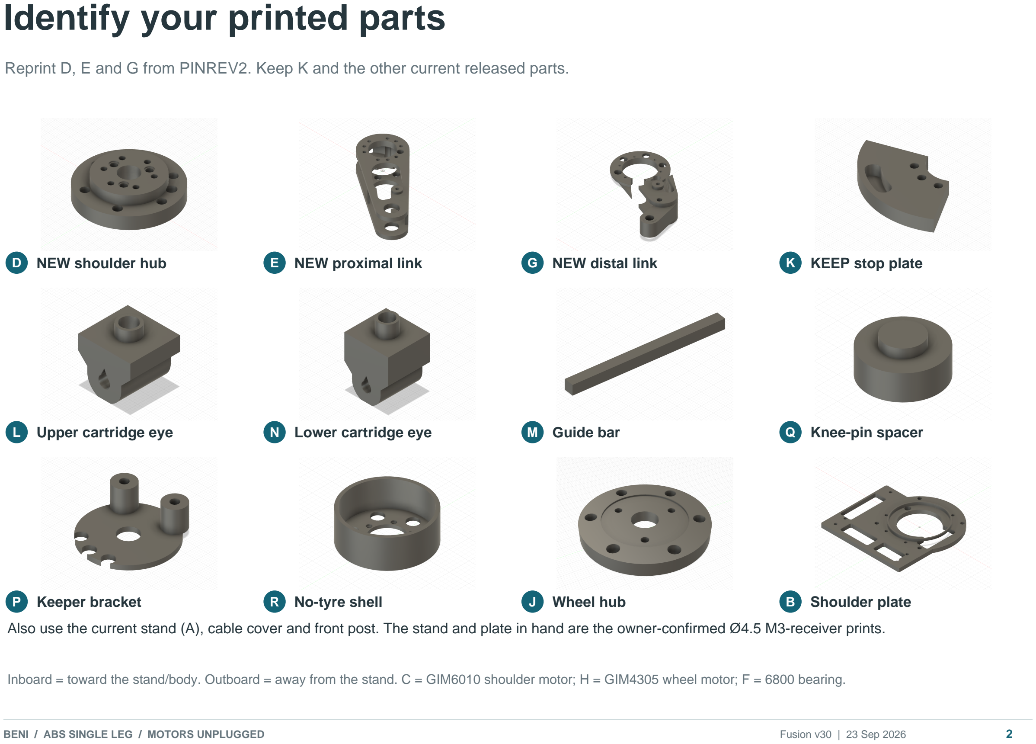
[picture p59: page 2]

Reprint D, E and G from PINREV2. Keep K and the other current released parts.

D NEW shoulder hub | E NEW proximal link | G NEW distal link | K KEEP stop plate
L Upper cartridge eye | N Lower cartridge eye | M Guide bar | Q Knee-pin spacer
P Keeper bracket | R No-tyre shell | J Wheel hub | B Shoulder plate
Also use the current stand (A), cable cover and front post. The stand and plate in hand are the owner-confirmed Ø4.5 M3-receiver prints.

Inboard = toward the stand/body. Outboard = away from the stand. C = GIM6010 shoulder motor; H = GIM4305 wheel motor; F = 6800 bearing.

BENI / ABS SINGLE LEG / MOTORS UNPLUGGED | Fusion v30 | 23 Sep 2026 | 2

# 01 Fit the two knee bearings

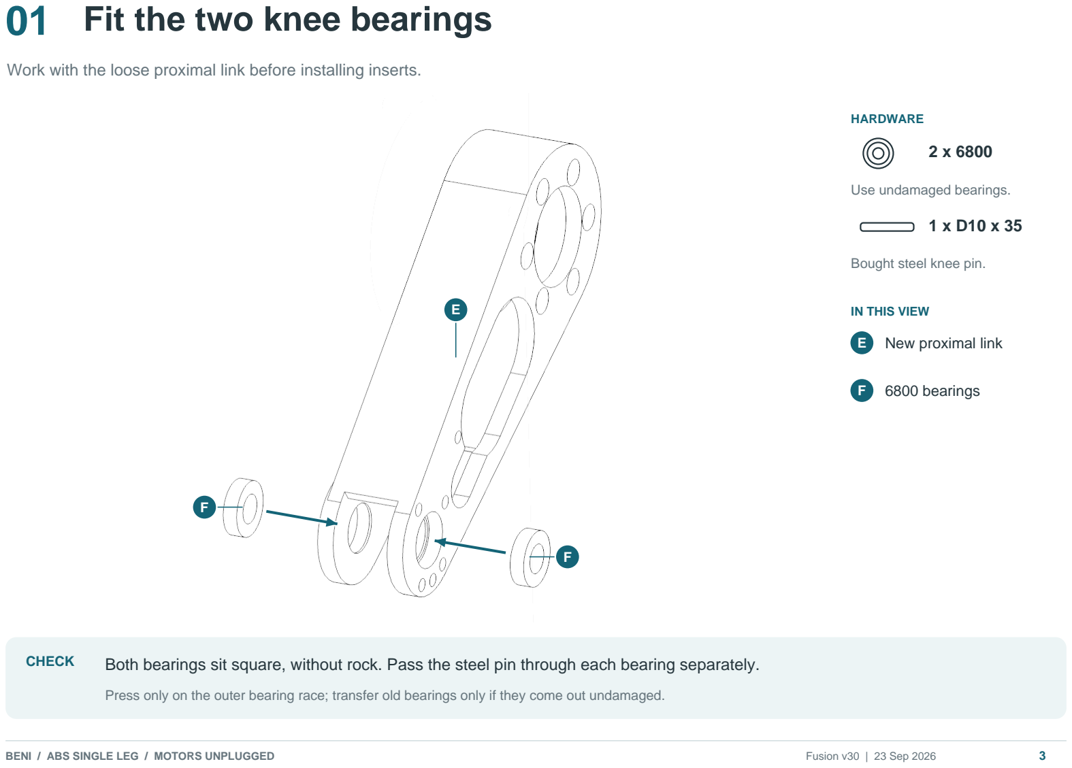
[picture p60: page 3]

Work with the loose proximal link before installing inserts.

E

F

F

HARDWARE

### 2 x 6800

Use undamaged bearings.

### 1 x D10 x 35

Bought steel knee pin.

IN THIS VIEW
E New proximal link

F 6800 bearings

CHECK | Both bearings sit square, without rock. Pass the steel pin through each bearing separately.
| Press only on the outer bearing race; transfer old bearings only if they come out undamaged.
BENI / ABS SINGLE LEG / MOTORS UNPLUGGED | Fusion v30 | 23 Sep 2026 | 3

# 02 Insert the new hub and proximal link

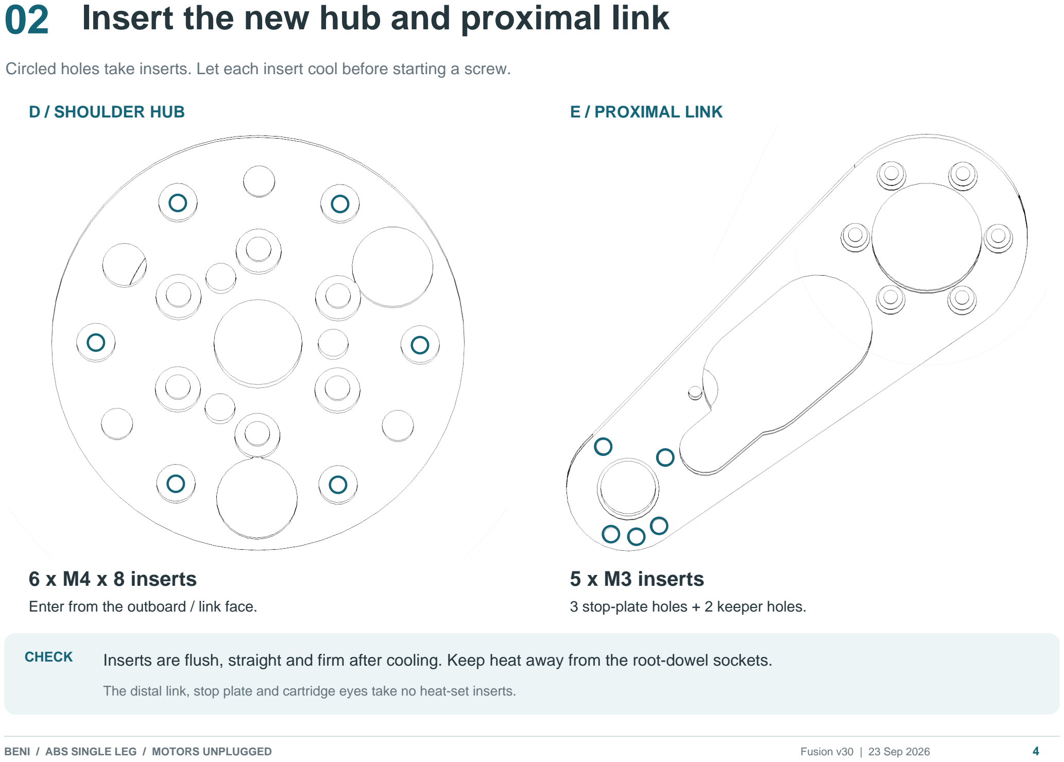
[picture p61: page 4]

Circled holes take inserts. Let each insert cool before starting a screw.

D / SHOULDER HUB | E / PROXIMAL LINK
6 x M4 x 8 inserts | 5 x M3 inserts
Enter from the outboard / link face. | 3 stop-plate holes + 2 keeper holes.
CHECK | Inserts are flush, straight and firm after cooling. Keep heat away from the root-dowel sockets.

The distal link, stop plate and cartridge eyes take no heat-set inserts.

BENI / ABS SINGLE LEG / MOTORS UNPLUGGED | Fusion v30 | 23 Sep 2026 | 4

# 03 Finish the exposed insert receivers

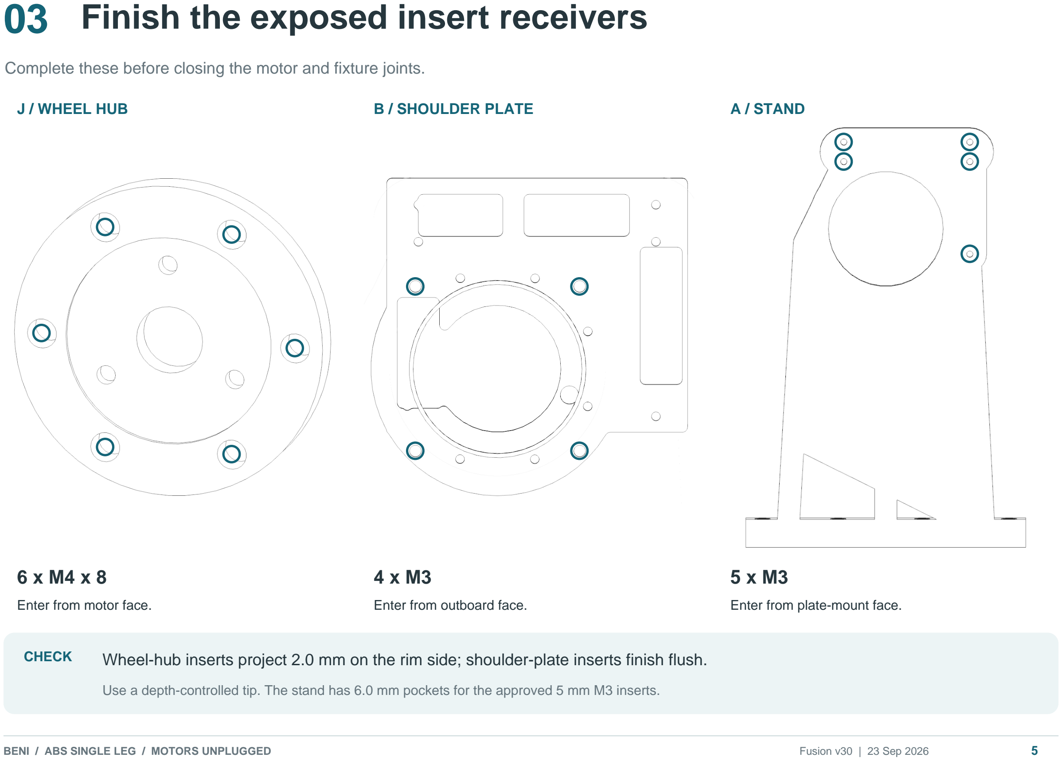
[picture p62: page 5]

Complete these before closing the motor and fixture joints.

J / WHEEL HUB

### 6 x M4 x 8

Enter from motor face.

B / SHOULDER PLATE

### 4 x M3

Enter from outboard face.

A / STAND

### 5 x M3

Enter from plate-mount face.

CHECK | Wheel-hub inserts project 2.0 mm on the rim side; shoulder-plate inserts finish flush.
| Use a depth-controlled tip. The stand has 6.0 mm pockets for the approved 5 mm M3 inserts.
BENI / ABS SINGLE LEG / MOTORS UNPLUGGED | Fusion v30 | 23 Sep 2026 | 5

# 04 Seat the three root dowels

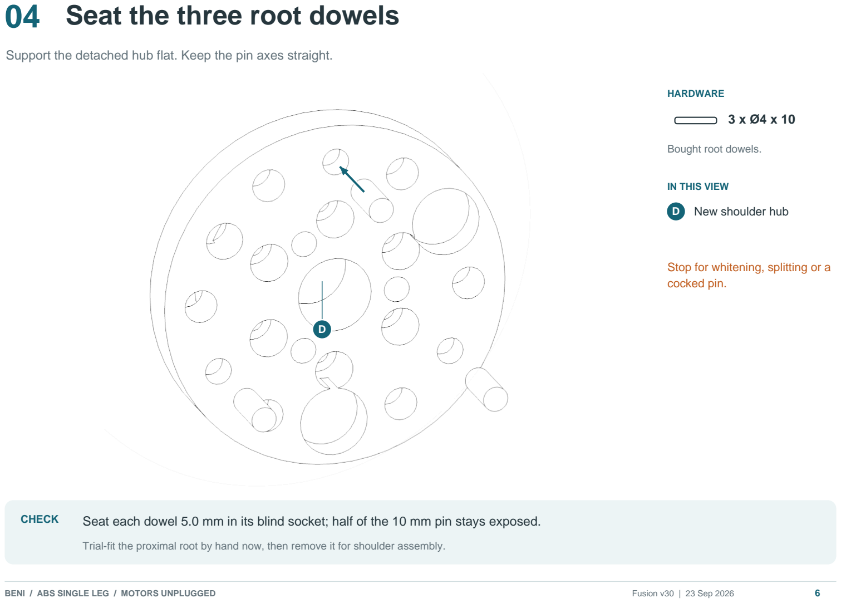
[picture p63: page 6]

Support the detached hub flat. Keep the pin axes straight.

D

HARDWARE

### 3 x Ø4 x 10

Bought root dowels.

IN THIS VIEW
D New shoulder hub

Stop for whitening, splitting or a cocked pin.

CHECK | Seat each dowel 5.0 mm in its blind socket; half of the 10 mm pin stays exposed.
| Trial-fit the proximal root by hand now, then remove it for shoulder assembly.
BENI / ABS SINGLE LEG / MOTORS UNPLUGGED | Fusion v30 | 23 Sep 2026 | 6

# 05 Slide the plate over the bare rotor

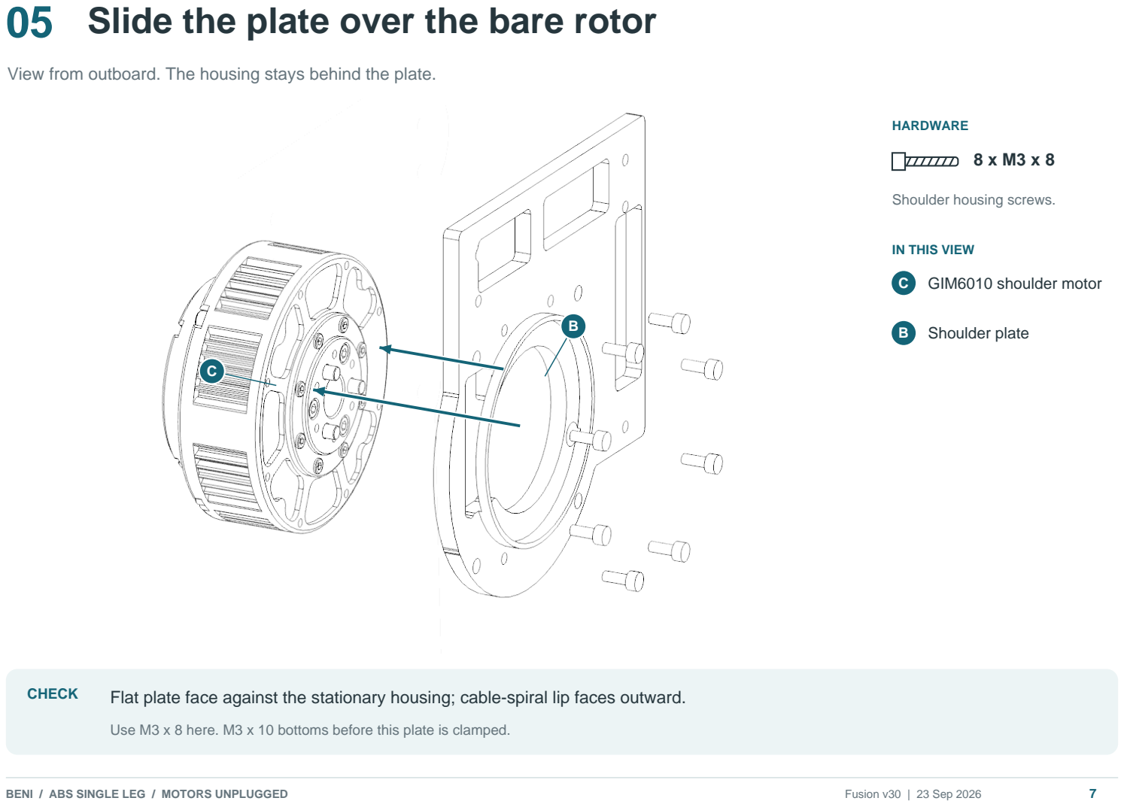
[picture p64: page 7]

View from outboard. The housing stays behind the plate.

C

B

HARDWARE

### 8 x M3 x 8

Shoulder housing screws.

IN THIS VIEW
C GIM6010 shoulder motor

B Shoulder plate

CHECK | Flat plate face against the stationary housing; cable-spiral lip faces outward.
| Use M3 x 8 here. M3 x 10 bottoms before this plate is clamped.
BENI / ABS SINGLE LEG / MOTORS UNPLUGGED | Fusion v30 | 23 Sep 2026 | 7

# 06 Fasten the shoulder to the stand

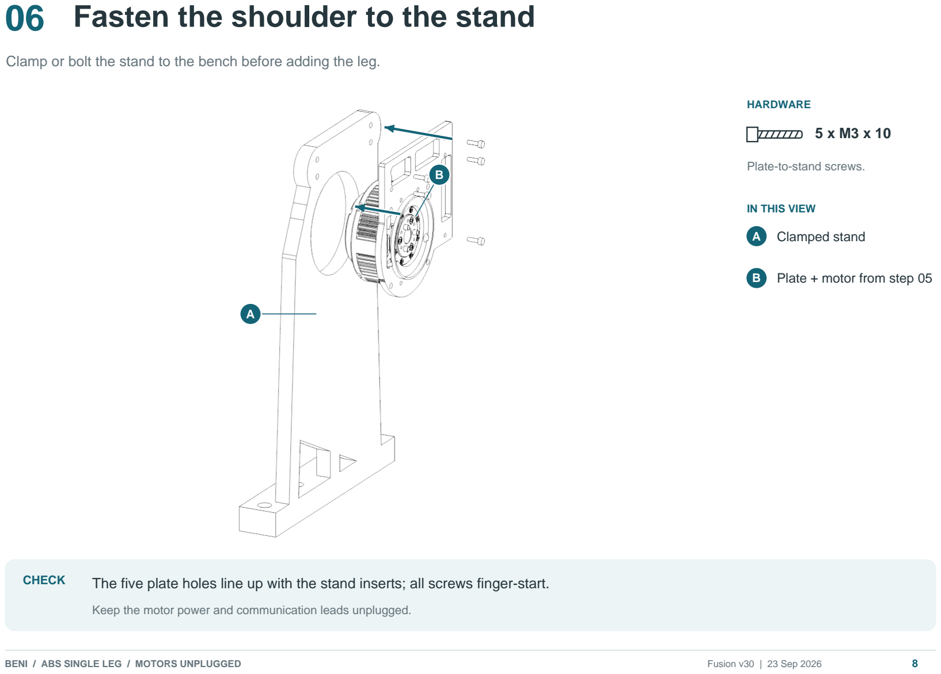
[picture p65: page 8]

Clamp or bolt the stand to the bench before adding the leg.

A

B

HARDWARE

### 5 x M3 x 10

Plate-to-stand screws.

IN THIS VIEW
A Clamped stand

B Plate + motor from step 05

CHECK | The five plate holes line up with the stand inserts; all screws finger-start.
| Keep the motor power and communication leads unplugged.
BENI / ABS SINGLE LEG / MOTORS UNPLUGGED | Fusion v30 | 23 Sep 2026 | 8

# 07 Route the cable; fit cover and post


Complete this area while you can still reach it.

1

2

HARDWARE

### 2 x M3 x 12

Upper post + cover positions.

### 2 x M3 x 10

Lower cover positions.

IN THIS VIEW
B Stationary shoulder plate
CHECK | 1: Cover closes the cable spiral. 2: Front post sits outside the cover.
| Route the real harness first. The printed cover has clearance holes and takes no inserts.
BENI / ABS SINGLE LEG / MOTORS UNPLUGGED | Fusion v30 | 23 Sep 2026 | 9

# 08 Fit the rotating shoulder hub


The motor factory pins enter the back of the new hub.

D

HARDWARE

### 6 x M3 x 10

Hub-to-motor output screws.

IN THIS VIEW
D New hub with root dowels
CHECK | Hub reaches the metal output face by hand; the three bought dowels point toward the link.
| The three motor factory pins and the three bought root dowels are separate interfaces.
BENI / ABS SINGLE LEG / MOTORS UNPLUGGED | Fusion v30 | 23 Sep 2026 | 10

# 09 Attach the proximal root


Support the far end of the link throughout this step.

D

E

HARDWARE

### 6 x M4 x 10

Link-to-hub clamp screws.

IN THIS VIEW
D Rotating shoulder hub

E New proximal link

CHECK | Faces meet on all three dowels before tightening. Every screw head sits flat.
| The six screws clamp the joint; do not use them to draw an incompatible fit together.
BENI / ABS SINGLE LEG / MOTORS UNPLUGGED | Fusion v30 | 23 Sep 2026 | 11

# 10 Mount the wheel motor


Detached distal link. View from inboard to show screw entry.

G

H

HARDWARE

### 6 x M2.5 x 12

Enter from the inboard side.

IN THIS VIEW
G New distal link

H GIM4305 wheel motor

CHECK | The motor seats on the distal wheel ring without screw pull-down.
| Keep the motor unplugged; support the loose assembly on the bench.
BENI / ABS SINGLE LEG / MOTORS UNPLUGGED | Fusion v30 | 23 Sep 2026 | 12

# 11 Fit the wheel output hub


View from outboard. The rim stays off for now.

H

J

HARDWARE

### 3 x M3 x 8

Wheel hub to motor output.

IN THIS VIEW
H Wheel motor

J Prepared wheel hub

CHECK | Hub seats by hand and all three output screws start freely.
| The six rim inserts were installed from the motor face in step 03.
BENI / ABS SINGLE LEG / MOTORS UNPLUGGED | Fusion v30 | 23 Sep 2026 | 13

# 12 Bring the distal receiver into the fork


The drawing isolates the links; support the fitted wheel motor and hub.

E

G

IN THIS VIEW
E Proximal fork + bearings

G Distal knee receiver

CHECK | The distal receiver sits in the gap between the two bearings; all three pin bores align.
| Slide in from the open side along the illustrated path. Keep the spring off.
BENI / ABS SINGLE LEG / MOTORS UNPLUGGED | Fusion v30 | 23 Sep 2026 | 14

# 13 Insert the steel knee pin


View from inboard. The pin travels through bearing - receiver - bearing.

1

HARDWARE

### 1 x D10 x 35

Bought steel knee pin.

IN THIS VIEW
E Proximal fork

G Distal receiver

CHECK | Firm-thumb insertion, full seating and hand withdrawal; no free spin or radial rock in the receiver.
| Prove withdrawal now, before adding the stop, cartridge or keeper. Stop if the pin seizes.
BENI / ABS SINGLE LEG / MOTORS UNPLUGGED | Fusion v30 | 23 Sep 2026 | 15

# 14 Capture the stop dowel


Fit the dowel first, then close it in with the new stop plate.

1
2

HARDWARE

### 1 x Ø6 x 10

Distal blind stop socket.

### 3 x M3 x 10

Stop plate to proximal inserts.

IN THIS VIEW
K New closed-skin stop plate
CHECK | Channel faces the dowel; closed skin faces outboard. Prove both stops with the spring absent.
| The plate bolts to the proximal link. Allowed knee range: -8° to +15°. No glue or press fit here.
BENI / ABS SINGLE LEG / MOTORS UNPLUGGED | Fusion v30 | 23 Sep 2026 | 16

# 15 Place the upper cartridge eye


Keep the supported knee at its -8° extension stop.

L

IN THIS VIEW
E Proximal upper clevis

L Upper cartridge eye

CHECK | The side pivot passage aligns with the clevis. The raised round spring pilot faces the lower eye.
| The round pilot hole carries the guide; the pointed-roof side hole carries the clevis pin.
BENI / ABS SINGLE LEG / MOTORS UNPLUGGED | Fusion v30 | 23 Sep 2026 | 17

# 16 Pin the upper eye


View from inboard. Add the washer and supplied cotter on the outboard end.

1

2

HARDWARE

### 1 x M4 x 40

Head stays inboard.

### 1 x M4 washer

ISO 7089 steel washer.

IN THIS VIEW
L Upper cartridge eye

Retention order: pin head / printed joint / steel washer / supplied cotter.

CHECK | Pin passes by hand. Washer rests on the printed outboard face; supplied cotter is fully seated.
| Orient the cotter radially away from the knee. No loose printed spacers.
BENI / ABS SINGLE LEG / MOTORS UNPLUGGED | Fusion v30 | 23 Sep 2026 | 18

# 17 Guide first, then spring


Cartridge close-up with the surrounding links hidden. Keep the knee at -8°.

L

M

N

1 / GUIDE INTO ROUND PILOT HOLE | 2 / SPRING OVER GUIDE; LOWER EYE FOLLOWS
CHECK | Both raised pilots face the spring. The lower eye slides freely on the guide.
| Use the owned OD18 / ID9 / 50 mm spring. Orange spring symbol is schematic.
BENI / ABS SINGLE LEG / MOTORS UNPLUGGED | Fusion v30 | 23 Sep 2026 | 19

# 18 Pin the lower cartridge eye


Bring the lower eye into the distal clevis with the knee still at -8°.

N

HARDWARE

### 1 x M4 x 40

Enter inboard to outboard.

### 1 x M4 washer

Then the supplied cotter.

IN THIS VIEW
G Distal lower clevis

N Lower cartridge eye

Turn the cotter radially away from the knee. Seat it fully without reshaping it.

CHECK | The lower pin passes with fingertip pressure. Washer and cotter are on the outboard end.
| Stop if more than slight hand compression is needed; do not pull the eye in with a pin or clamp.
BENI / ABS SINGLE LEG / MOTORS UNPLUGGED | Fusion v30 | 23 Sep 2026 | 20

# 19 Fit the outboard knee-pin keeper


The cartridge is hidden in this close-up for visibility.

Q

P

HARDWARE

### 2 x M3 x 16

Bracket to proximal inserts.

IN THIS VIEW
Q Knee-pin spacer

P Keeper bracket

CHECK | The spacer locator enters the bracket center hole; the bracket sits on its two mounting positions.
| This limits outboard travel only. Keep hand control of the distal side to prevent inboard escape.
BENI / ABS SINGLE LEG / MOTORS UNPLUGGED | Fusion v30 | 23 Sep 2026 | 21

# 20 Attach the no-tyre shell


The wheel assembly remains suspended throughout this test.

J

R

HARDWARE

### 6 x M4 x 8

Shell to wheel-hub inserts.

IN THIS VIEW
J Wheel output hub

R No-tyre test shell

CHECK | Shell seats without force; all six screws start freely. Leave the TPU tyre off.
| Do not place the test shell on the bench or floor.
BENI / ABS SINGLE LEG / MOTORS UNPLUGGED | Fusion v30 | 23 Sep 2026 | 22

# 21 Check motion by hand


Stand clamped. Both motors unplugged. Wheel clear. One hand contains the distal side.

-8° / EXTENSION STOP | +15° / FLEXION STOP

-8° 0° +5° +10° +15°

CHECK | Move slowly between the stops. Observe smooth movement and the settle / return tendency.
| Stop for cracks, binding, coil contact, guide escape, moving pins, loose cotters or stop bypass.
BENI / ABS SINGLE LEG / MOTORS UNPLUGGED | Fusion v30 | 23 Sep 2026 | 23

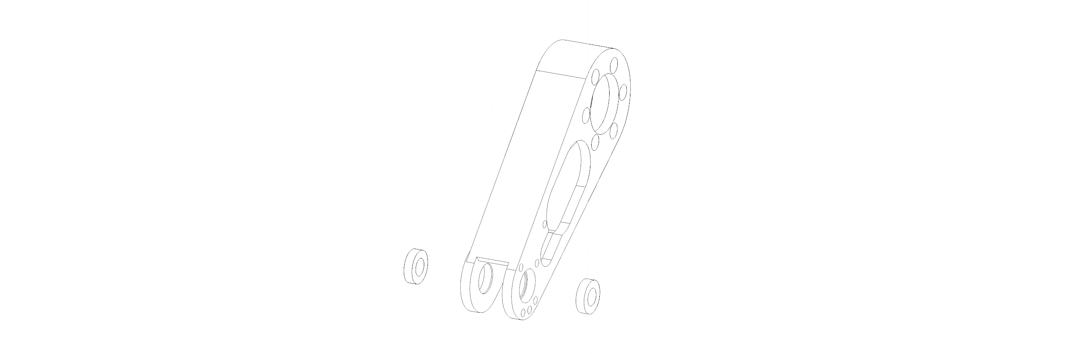
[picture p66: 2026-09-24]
docs/assembly/manual/views/01_bearings.png

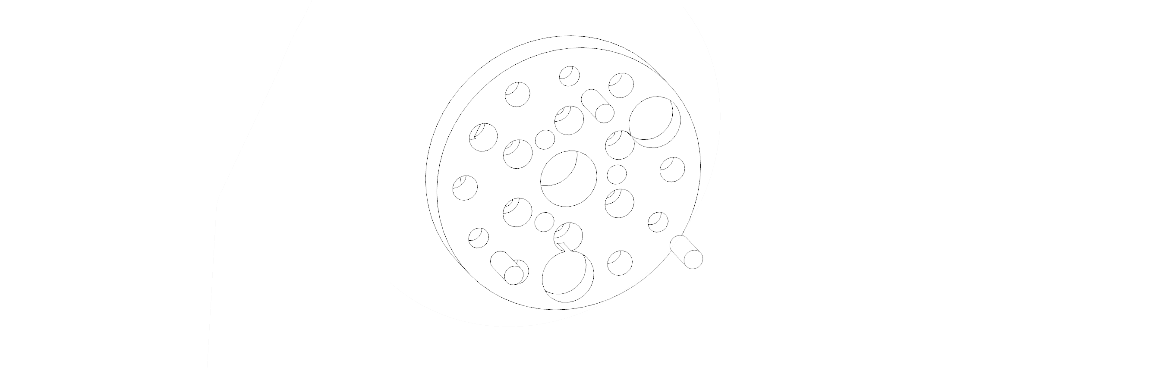
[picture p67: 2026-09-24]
docs/assembly/manual/views/02_hub_dowels.png

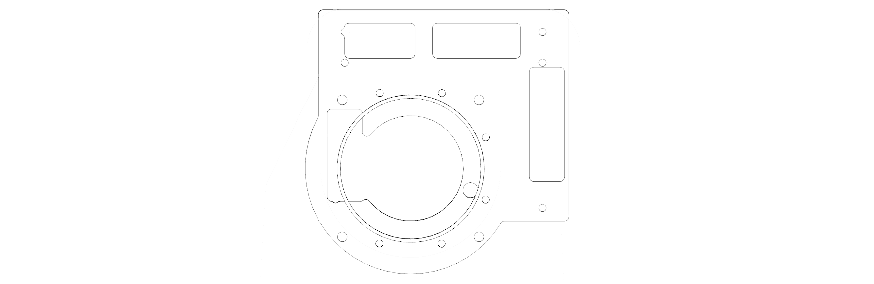
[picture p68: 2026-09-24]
docs/assembly/manual/views/27_plate_inserts.png

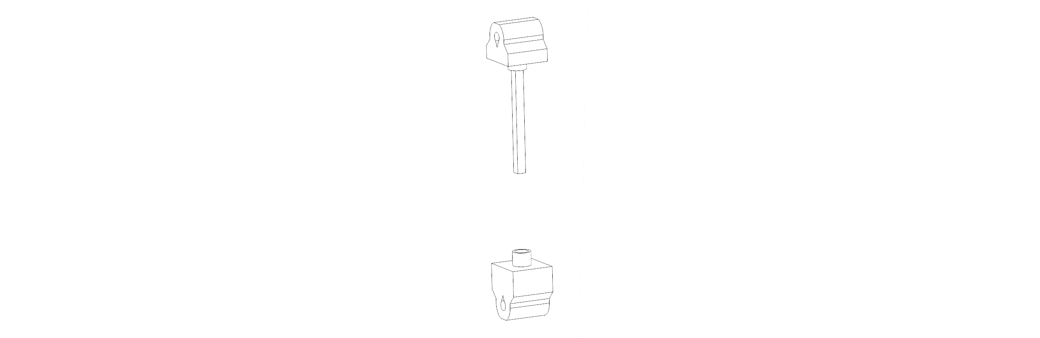
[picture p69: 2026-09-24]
docs/assembly/manual/views/24_cartridge.png

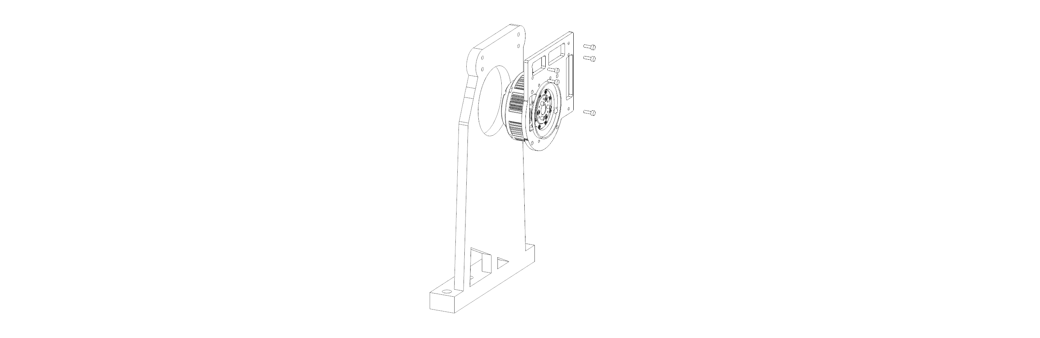
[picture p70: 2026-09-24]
docs/assembly/manual/views/04_stand.png

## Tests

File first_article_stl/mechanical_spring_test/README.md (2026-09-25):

# Unpowered ABS spring-mechanical test

**Spring-installed motion HOLD — September 24:** the owner reports spring
bowing and sideways escape during compression after assembly. Keep motors
unplugged and do not repeat spring compression pending diagnosis. Spring-free,
supported inspection may continue. [Physical failure record](../../evidence/assembly/2026-09-24_spring_escape/).
The spring-installation and hand-test steps below are held.

> **September 21 update:** the original shoulder hub, proximal link, distal
> link, stop plate, Ø4 × 32 clevis pins, and Ø6 × 9 stop dowel are superseded.
> Use the [ordered-pin replacement traveller](../ordered_pin_integration/) for
> those parts and hardware. This directory remains current only for the two
> cartridge eyes, guide bar, D10 knee-pin spacer, bracket keeper, no-tyre wheel
> shell, and the hand-test limits below.

**Owner update, September 22:** the owner reports that all parts from this
earlier mechanical-test print batch were printed. The six retained files below
can be reused after physical inspection and detached fit checks. The September 23 [audit](../../evidence/assembly/2026-09-23_mechanical_reprint_audit/)
confirms these six retained files remain correct. Reprint the PINREV2 hub and
both links; retain the ordered-pin closed-skin stop plate. The Amazon pins are
in hand. Use that release's consolidated assembly order.

This batch completes a supported, motor-unplugged single-leg mechanical article
around the owned **OD18 / ID9 / 50 mm** yellow spring. It is a hand-operated
fit and behavior test. It does not establish spring rate, payload, ground
traction, powered-motion clearance, structural life, or a safe two-leg build.

The revised cartridge has 50.000 mm between its spring seats at the **-8°
extension stop**, so the spring installs with nominally zero compression. The
new printed stop limits the test to **+15°**, where Fusion gives a 39.760 mm
installed spring length and **10.240 mm compression**. The actual equilibrium
angle cannot be predicted until the spring rate is measured: this compression
spring opposes knee flexion, while the leg's self-weight flexes the knee.

## Retained print files

Import every `PRINT_ORIENTED` STL unchanged. Do not rotate, scale, or apply
hole compensation.

| File | Qty | Purpose and bed orientation |
|---|---:|---|
| [`ABS_TEST_Cart_Upper_Eye_50mm_AXIS_UP_PRINT_ORIENTED.stl`](ABS_TEST_Cart_Upper_Eye_50mm_AXIS_UP_PRINT_ORIENTED.stl) | 1 | Upper eye, spring axis vertical; use a brim |
| [`ABS_TEST_Cart_Lower_Eye_50mm_AXIS_UP_PRINT_ORIENTED.stl`](ABS_TEST_Cart_Lower_Eye_50mm_AXIS_UP_PRINT_ORIENTED.stl) | 1 | Lower eye, spring axis vertical; use a brim |
| [`ABS_TEST_Cart_Guide_Bar_50mm_FLAT_PRINT_ORIENTED.stl`](ABS_TEST_Cart_Guide_Bar_50mm_FLAT_PRINT_ORIENTED.stl) | 1 | Removable 3.8 mm square guide, long face on the bed |
| [`ABS_TEST_Knee_Pin_Outboard_Spacer_PRINT_ORIENTED.stl`](ABS_TEST_Knee_Pin_Outboard_Spacer_PRINT_ORIENTED.stl) | 1 | Locates in the encoder bracket and limits outboard pin travel |
| [`ABS_TEST_Knee_Encoder_Bracket_PIN_KEEPER_PRINT_ORIENTED.stl`](ABS_TEST_Knee_Encoder_Bracket_PIN_KEEPER_PRINT_ORIENTED.stl) | 1 | Existing bracket reused as the outboard keeper plate |
| [`ABS_TEST_Wheel_Rim_NoTyre_PRINT_ORIENTED.stl`](ABS_TEST_Wheel_Rim_NoTyre_PRINT_ORIENTED.stl) | 1 | Support-free suspended-test wheel shell; broad web face on the bed |

Use the same enclosed ABS profile as the passed dimensional articles: **0.20 mm
layers, 4 walls, 5 top and 5 bottom layers, 30% infill**. Disable supports for
all six current files. A brim is required on both cartridge eyes and is permitted on
the other parts if the tuned ABS profile normally uses one. The eye pivot
passages have self-supporting pointed roofs; inspect them after printing and do
not drill, file, sand, heat, or force a failed fit.

Print the two eyes, guide and spacer together only if that plate has stable ABS
results. Print the wheel shell alone. Keep the labels with the two cartridge
eyes after removal.

## Existing parts required

This batch assumes these already released parts are printed or will be printed
from the active queue:

- the ordered-pin proximal link, with five inserts installed;
- the ordered-pin distal link after its Ø10.30 × 20.0 receiver passes physical
  insertion, withdrawal, spin, rock, and axial-play checks;
- the ordered-pin shoulder hub, wheel hub, shoulder plate as required, and the
  clamped Mode A stand.

Use the owned 50 mm spring, both 6800 bearings, the 10 × 35 steel knee pin,
**2 × M4 × 40 clevis pins with supplied cotters**, **2 × ISO 7089 M4 washers**,
**1 × Ø6 × 10 stop dowel**, 3 × M3 × 10 stop-plate screws, 2 × M3 × 16 bracket
screws, and 6 × M4 × 8 wheel-rim screws. The shoulder root also uses 3 ×
Ø4 × 10 dowels. Do not substitute printed cartridge pins, a printed stop dowel,
or printed clevis spacers. If the ordered metal hardware is not in hand, stop
before installing the spring.

## Detached fit checks

The guide bar does **not** enter the teardrop-shaped side passage. That passage
is the horizontal Ø4 clevis-pin hole; its pointed roof is only a self-supporting
print feature. Insert the guide along the spring axis through the round hole in
the raised Ø8 cylindrical spring pilot. The guide then runs through the center
of the spring.

1. Slide the guide bar into the upper eye through the round opening in its
   raised spring pilot. It must bottom by hand and pull out by hand. Fusion
   provides 0.626 mm diametral room around the bar's diagonal; any binding or
   layer split is a failed print.
2. Slide the lower eye over the free end of the guide. It must move through the
   full available travel without catching.
3. Place each end of the free spring over its Ø8 pilot. Both ends must sit flat
   without spreading, force, or visible rocking, matching the passed detached
   cap test.
4. Pass each Ø4 clevis pin through its printed eye by hand. The pointed roof is
   print clearance above the pin, not a second working position.
5. Seat the spacer's Ø7.6 locator in the encoder bracket's Ø8 center hole. It
   must sit flat and remain removable.

## Assembly order

Keep both motors unplugged throughout. Clamp or bolt the Mode A stand to the
bench before the leg is attached, support the knee and wheel, and keep the wheel
clear of the floor.

1. Install the two bearings and assemble the proximal and released distal links
   with the steel knee pin. Confirm the pin still withdraws by hand before
   adding the spring hardware.
2. Place the Ø6 × 10 steel dowel in the ordered-pin distal link's blind socket
   and bolt the closed-skin stop plate to the three proximal-link inserts with
   M3 × 10 screws. The plate captures the dowel; do not glue or force it.
   Hand-pose the spring-free knee and confirm it stops at -8° and +15°.
3. Put the knee at the -8° stop. Insert the upper cartridge eye radially into
   its proximal-link clevis. Insert the upper M4 × 40 pin inboard-to-outboard,
   add one specified M4 washer, orient the cotter radially away from the knee,
   and seat the supplied cotter fully without bending or reshaping it.
4. Insert the guide bar through the round center of the upper eye's raised Ø8
   pilot. Slide the free spring over the guide and onto that pilot. With the
   lower eye's raised pilot facing the other spring end, slide its round center
   opening over the exposed guide, then bring its pivot into the distal-link
   clevis. The lower M4 × 40 pin must enter with fingertip pressure. Add its M4
   washer and supplied cotter in the same orientation. If more than slight hand
   compression is needed, stop and record the achieved gap; do not pull the
   parts together with a pin, screw, clamp, or tool.
5. Put the printed spacer on the encoder bracket with its small locator in the
   bracket center hole. Bolt the bracket to the two proximal-link inserts with
   M3 × 16 screws. The spacer should sit 0.3 mm beyond the modeled knee-pin end
   and leave 0.5 mm to the bracket plate. It limits outboard pin travel; the
   firm-thumb receiver fit and the operator's hand remain the inboard control
   for this test.
6. Bolt the no-tyre test wheel shell to the accepted wheel hub with six M4 × 8
   screws. This shell omits the unsupported inner ledge, tyre bead, and inboard
   flange. Do not fit the TPU tyre and do not put this shell on the floor.

Fusion found clear radial paths for both cartridge eyes, clear 40 mm insertion
paths for the guide and both clevis pins, a clear 30 mm spring-over-guide path,
and a clear 40 mm outboard service path for the test wheel shell.

## Hand test

Keep one hand on the distal link or wheel at all times. Move slowly through
**-8°, 0°, +5°, +10°, and +15°**. Never push through either stop.

At each position, reduce hand support gradually and observe whether the
self-weight/spring balance settles, returns toward extension, or moves toward
the +15° stop. A useful result is a smooth, repeatable tendency with no spring
bowing, guide binding, eye cracking, pin migration, or stop-plate marking. It is
also valid for the leg to settle at an undesired angle; that result tells us the
unknown spring rate does not balance this ABS article as hoped.

Stop immediately for coil contact, scraping, guide buckling, a click or crack,
visible whitening, a moving knee pin, a loose clevis clip, or a stop that does
not engage. Do not add weight, allow ground contact, bounce the leg, backdrive
or power either motor, or use the result as a payload test.

The exact Fusion sweep, service paths, stop-overtravel proof, print orientations,
and mesh hashes are in [`fusion_manifest.json`](fusion_manifest.json) and the
[release evidence](../../evidence/assembly/2026-09-17_abs_spring_mechanical_test/).

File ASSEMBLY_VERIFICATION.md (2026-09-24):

# Physical assembly-path verification

An interference-free final CAD pose is necessary, but it is not a build
release. Every released part or subassembly also needs a physically achievable
installation and removal path.

## Required release gate

Before a part is sent to the printer or added to an assembly instruction, record
all of the following:

1. **Order** — the parts and captive hardware that must be installed first.
2. **Insertion path** — the direction and intermediate poses used to reach the
   final CAD pose. Check the full path in Fusion, not only the endpoints.
3. **Fastener and tool access** — screws must be startable and torqueable with
   the surrounding parts present. Screws must not be used to pull a mismatched
   print into place.
4. **Cable path** — connectors, strain relief, and minimum bend space must remain
   installable during the stated sequence.
5. **Service path** — identify what must be removed to replace the part and make
   sure that removal does not require damaging another component.
6. **Physical rehearsal** — for a first article, repeat the sequence with the
   real hardware and record the result before structural release.

Use these status labels in build records:

- `CAD PATH VERIFIED` — Fusion was used to check intermediate poses and tool
  access, but the sequence has not yet been completed on the real hardware.
- `PHYSICAL ASSEMBLY VERIFIED` — the owner completed the sequence with the real
  parts without forcing, destructive rework, or fastener pull-down.
- `BLOCKED` — there is no demonstrated path, required hardware is missing, or a
  physical attempt failed. Do not release downstream parts that depend on it.

For each first-article batch, its local `README.md` is the build traveller: it
must state the exact sequence, current status, and evidence link. The canonical
fastener schedule and full robot assembly order remain in
[`beni_prototype1_bom_and_assembly.md`](beni_prototype1_bom_and_assembly.md).

The first recorded application of this gate is the GIM6010 shoulder stack:
[`evidence/shoulder_assembly/2026-08-23_plate_sequence/`](evidence/shoulder_assembly/2026-08-23_plate_sequence/).

The 2026-09-02 receiver audit added one concrete correction to that stack: the
old cable-cover screws entered from the inboard face and their heads collided
with the stand/chassis volume. The four inserts now live in the shoulder plate,
the cover is a clearance part, and M3 × 10 screws enter from the accessible
outboard face. Fusion verified 1.5 mm screw-tip clearance and zero stand
interference. The pictured insert and screw-direction map is
[`docs/assembly/heatset_receiver_map.md`](docs/assembly/heatset_receiver_map.md).
On 2026-09-14 the owner selected nominal Ø4.5 on the same-profile M3 ladder.
Fusion promoted that diameter into the active plate, proximal link and stand;
replace prior printed Ø4.0 receiver parts before insert installation.

The 2026-09-03 owned-M4 redesign adds a second explicit path condition. The
M4 × 8 wheel inserts install from the detached hub's motor face, pass through
the 6.0 mm hub, and finish with 2.0 mm projecting outboard. Fusion B-Rep checks
verify that all six projecting Ø5.5 label envelopes enter straight coaxial
Ø6.0 × 2.2 reliefs in `Wheel_Rim_L`; after the six screws are removed, the rim
services straight outboard along the same open paths. The owner-selected
Ø5.3 receiver was promoted through Fusion on 2026-09-04. The hub is an ABS
print release. The final tyre-compatible rim remains held for the separate
printability finding below; the September 17 no-tyre shell is a different,
suspended-test-only part.

The same rerun found a separate `RIG_Cable_Post_A`/cable-cover overlap. The
2026-09-05 redesign moves the post outside the cover; its eye remains open
beyond the cover edge. Actual harness routing still needs physical rehearsal.

## 2026-09-04 release checks and new blockers

[Fusion B-Rep path and print audit](evidence/inserts/2026-09-04_m4_coupon_pass/fusion_paths_and_print_audit.json)
checks each axial path from +40 mm to the final pose in 0.5 mm steps. The
bare-rotor plate, Ø4.15 ABS hub, cable cover, proximal-link body, wheel hub and
rim body paths have zero intersections; reverse motion provides their removal
path. The wheel’s six M4 screws also have clear insertion paths. The shoulder
hub is released for detached insert installation and unplugged motor fit.

**Historical 2026-09-04 link failure, corrected 2026-09-05:** two M4 × 10
heads hit the internal wall on a straight approach. The current link extends
all six access passages through that wall and shortens the lightening opening
to restore a complete seat under the sixth head. New exact continuous swept
head/shank/driver envelopes and seat-support checks pass. The owner accepted
the new hub's insert installation; on September 7 the owner also confirmed
the corrected link and all six screw seats. See the
[physical result](evidence/assembly/2026-09-07_owner_mockup/) and
[current audit](evidence/assembly/2026-09-05_access_fix/).

**Final tyre-compatible wheel-rim printing remains BLOCKED.** With the broad web face on the bed,
the annular underside at source y = 72 spans r = 30…44: a 14 mm unsupported
inward ledge. The outer retaining flange also has an overhang. The former
no-support claim is withdrawn. A printable solution must preserve the frozen
stack and keep support off the tyre, insert reliefs and mating/service faces.

The shoulder hub’s two Ø11 blind-relief ceilings and motor counterbore
shoulders are controlled bridges. The wheel-hub counterbore shoulders and
stand’s Ø4.5 blind-pocket roofs also bridge. Inspect their undersides on the
first ABS articles; the bores remain vertical and no slicer support is allowed
on their functional surfaces. The full wired/stand article is still gated by
actual harness routing, floor disposition, real knee pin/retention and electronics checks.

## 2026-09-05 access and assembly-order audit

[Ordered Fusion paths](evidence/assembly/2026-09-05_access_fix/ordered_paths.json)
check the link, cover, cable post and rim through 81 poses each. All 49 modelled
screw paths clear with the stated order. These constraints are part of assembly,
not optional workarounds:

- Fit housing screws with the proximal link, cover and post absent.
- Attach the panel to the stand before adding the front cable post.
- Fit knee-stop screws before the encoder bracket; remove the bracket to
  withdraw those screw heads. Its Ø5 access openings are for a driver.
- Fit/service wheel-motor housing screws with the leg supported off the stand.
- Remove the link before removing the cover; reverse the remaining sequence.

[The ABS export report](evidence/assembly/2026-09-05_access_fix/proximal_release.json)
checks both continuous bearing insertion/removal envelopes, full root screw
lands, topology and supporting plane. The front post's Ø6 probe passes its
open Ø8 eye with the cover fitted. The exact iron tip, cable connector, tie and
bend-radius fit remain physical checks; these envelopes do not assert a full
wired or structural release.

## 2026-09-06 supported knee mock-up

The [interim batch](first_article_stl/knee_mockup/) is `CAD PATH VERIFIED`
for two detached, supported links. A provisional distal tongue with its thrust
extensions omitted enters the fork radially with both bearings installed;
the temporary Ø9.7 pin then slides through all three bores. No spacers, collar,
spring cartridge, motors or wiring are present. Support removal, radial
insertion, continuous pin envelopes and sampled hand poses are recorded in
the [Fusion evidence](evidence/assembly/2026-09-06_supported_knee_mockup/).
The [September 7 owner report](evidence/assembly/2026-09-07_owner_mockup/)
confirms printing, successful provisional assembly, free supported knee
movement and easy pin removal: `PHYSICAL ASSEMBLY VERIFIED` for the supported
provisional hand fit. The shoulder motor appears attached in the photo; the
report does not expand the detached-link traveller to motor loads or power.
Detailed support-removal quality was not separately reported. Both spring
caps pass their detached, uncompressed fit check. These results do not release
the final distal/steel-pin/retention stack or spring cartridge.

## 2026-09-15 real steel pin in provisional shin

The real-pin gate is now `PHYSICAL FIT FAILED` for the provisional shin bore.
The owner fully inserted one received metal pin through both installed bearings
and the provisional shin, then had to break the printed shin pieces to recover
it. The owner isolated the seizure to the shin's nominal Ø10 bore; the bearings
were snug but were not the cause of the trapped assembly.

Do not repeat the nominal Ø10 bore in another link. The bearing result remains
incomplete until the pin candidates are inserted and removed through each
bearing separately without the printed link. Nominal Ø10.25 passed the initial
19.0 mm coupon under firm thumb pressure, and the owner selected Ø10.30 while
the receiver was expected to span 21.6 mm. Fusion's final service audit found
that copied sleeve span overlapped both bearing pockets, so the saved v26 source
now uses the clear 20.0 mm fork gap with 0.8 mm axial clearance per side.
Printability, support-removal, link/pin insertion and mesh checks pass, and the
bed-ready fit article is released. The first print must still prove firm-thumb
insertion, hand withdrawal, no free spin or rock and acceptable axial play.
Final retention and encoder coupling remain required before powered use. The
controlled September 17 unpowered spring article uses an outboard
spacer/bracket keeper plus hand containment and depends on this physical gate.
[Owner result](evidence/knee_fit/2026-09-15_steel_pin_provisional_shin/) ·
[Fusion release](evidence/knee_fit/2026-09-16_distal_d10p30_release/).

## 2026-09-17 unpowered spring-mechanical article

The [local traveller](first_article_stl/mechanical_spring_test/) is `CAD PATH
VERIFIED` for the complete supported single-leg sequence. Fusion sampled every
integer knee pose from -8° through +15°, found zero link/cartridge/spring-envelope
interference, and proved contact at both stops by 0.5° of overtravel. It also
verified radial insertion for both eyes, axial insertion for the guide and
spring, both clevis-pin paths, the steel knee-pin path and 40 mm wheel-shell
service travel. All seven exported meshes are closed manifolds on their stated
support planes.

The test remains `PHYSICAL ASSEMBLY PENDING`. Its Ø4 × 32 clevis-pin, Ø6 × 9
stop-dowel, and original stop-plate instructions are superseded by the
September 21 ordered-pin release below. The cartridge eyes, guide, D10 spacer,
bracket keeper, and no-tyre wheel shell remain current.

## 2026-09-21 ordered-pin integration

The [ordered-pin traveller](first_article_stl/ordered_pin_integration/) is `CAD
PATH VERIFIED` for the purchased Ø4 × 10, M4 × 40, and Ø6 × 10 pin families.
The new shoulder hub and proximal root use three face-locating dowels with a
press side, slip side, and screw-clamped axial capture. Both cartridge pivots
use integral Ø14 lands that make a 34.0 mm retained stack; one ISO 7089 M4
washer separates each printed land from its supplied cotter, with 0.4 mm
conservative clearance to the retaining-hole edge. The stop dowel is captured
between a blind distal socket and a closed 0.8 mm stop-plate skin, with 0.3 mm
axial clearance and no glue or press-fit dependency.

Fusion preserved the accepted proximal and distal print datums, passed both
40 mm clevis insertion paths, all 24 allowed knee poses, and positive stop
contact at 0.5° of overtravel. All four replacement meshes are closed
manifolds on their stated bed planes. [Numeric release evidence](evidence/assembly/2026-09-21_ordered_pin_integration/).

The release remains `FINAL-PART HAND FIT PENDING`: the actual ordered pins have
already selected both Ø4.25 printed interfaces without measurement. **[SUPERSEDED
2026-09-23: PINREV2 uses the owner-requested Ø4.30; see the regression gate
below.]** Visually
inspect the hardware and complete the traveller's final-part hand-fit checks.
Do not compensate a failed interface by drilling, filing, hammering, or screw
pull-down. Clamp the stand, unplug both motors, keep the wheel clear, contain
the distal side by hand, install the spring at the -8° stop, and move slowly no
farther than +15°. This procedure observes self-weight equilibrium; it does not
validate spring rate, solid height, ground contact, structural load, or powered
motion.

On September 22 the owner reported that the four revised parts and all parts
from the earlier mechanical-test print batch are printed, and that the Amazon
pin families are in hand. This closes their printing and receipt gates only;
the [owner material record](evidence/assembly/2026-09-22_owner_printed_parts_and_pins/)
does not claim completed bearing, insert, pin, stop or spring checks. Follow
the [current ordered assembly](first_article_stl/ordered_pin_integration/README.md#ordered-assembly)
with the retained September 17 cartridge and wheel-shell parts.

## 2026-09-22 ordered-pin fit ladders

The two [ordered-pin fit ladders](first_article_stl/ordered_pin_fit/) are
`OWNER SELECTED / CAD PROMOTED`. The real pins were used directly; no
measurement was part of the gate.

The root ladder reproduces the hub's bed-facing 5.0 mm blind socket and 3.0 mm
closed floor at Ø4.05…4.25 in 0.05 mm steps. The owner selected the largest,
farthest-from-marker station, nominal **Ø4.25**, reporting a relatively tight
fit that presses in by thumb and pulls out with pliers. Fusion v29 uses this in
the retained hub side; the link side remains an intentional Ø4.25 × 5.2 slip
fit. Reject whitening or cracking during final-hub installation.

The clevis ladder reproduces the Ø14 boss and the longest restrictive link
land at 9.0 mm, with Ø4.15…4.35 passages in 0.05 mm steps. The owner selected
the middle station, nominal **Ø4.25**, and reported that it works well. Fusion
v29 uses this for both link passages. The intervening cartridge-eye passages
remain Ø4.4 × 19 mm. Final link/eye stacks still require hand insertion and
withdrawal checks. A continuous 34 mm coupon was rejected because that
dimension is the retained stack, not continuous bore material, and would bias
the result loose.

The Ø6 × 10 stop pin remains excluded from fit calibration because its Ø6.2
socket is deliberately loose and the closed stop-plate skin provides axial
capture. Fusion v29 and the refreshed bed-ready hub/link exports have passed
the mechanical audit and are released for printing. **[SUPERSEDED 2026-09-23:
the v29 distal export had lost its Ø10.30 receiver; PINREV2 replaces the hub
and both link files.]**

## September 23 mechanical release regression gate

The September 22 distal mesh failed its physical pin-fit check: a rebuild lost
the printed receiver and left Ø16. The [full 15-part audit](evidence/assembly/2026-09-23_mechanical_reprint_audit/)
supersedes the v29 release claim for that file. PINREV2 restores Ø10.30 × 20.0
and incorporates the owner's Ø4.30 root/clevis-link preference. Reprint the hub
and both links; keep the other current released parts subject to the audit's
stand/plate revision check and physical acceptance.

Run `mechanical_release_audit_fusion.assert_all()` before and after mechanical
motion/path checks, then validate each bed-ready mesh against the reviewed
baseline. Rebuild testing and deliberate missing/oversized/shortened receiver
mutations must demonstrate rejection. Cut operations must target only their
own bodies. Baseline updates require explicit design review, never automatic
acceptance of whatever a builder produced. No release may infer fit from a
filename, parameter constant, mesh volume or zero interference alone.

## September 24 cross-machine STL release gate

Tessellation is part of dimensional control, like print orientation. Fusion
2705.1.25 ignores the surface deviation, so its plain High export would print
the proximal Ø19.15 bearing seats 0.040 mm tighter across the flats than the
released file. Every print export now uses `stl_release`: a 0.004 mm chord on
the largest radius, measured, on any machine. `assert_export()` accepts the
pinned triangle fingerprint or a `mesh_fidelity()` proof that the mesh is the
reviewed B-Rep at its bed pose. Exporters retain pinned files that still match.
All 15 pinned files pass, the wrong-geometry controls fail, and both release
scripts complete on this machine without changing a released file.
[Evidence and rejected alternatives](evidence/assembly/2026-09-24_cross_machine_release_gate/).

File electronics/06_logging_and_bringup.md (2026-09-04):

# 06 — Logging, Telemetry and Bring-Up

Covers brief §10 deliverable **9** (bring-up plan), plus the instrumentation
that has to exist before Stage 3.

## 1. Why logging comes first

This robot fails in **20–200 ms events**: a landing impact is ~20 ms, a thrust
is 60–80 ms, a fall from vertical is ~300 ms. **You cannot debug any of that by
watching it, and you cannot debug it over a 50 Hz telemetry link either.**
Every hour spent on the logging pipeline before the first powered test saves a
day of guessing later.

Three tiers, all built in Stage 1:

| Tier | Path | Rate | Use |
|---|---|---|---|
| **1. Onboard binary** | microSD, FatFs | **1 kHz, all channels** | Post-mortem. The only tier that survives a fall. |
| **2. Live plot** | UDP → PlotJuggler | 100–200 Hz, ~20 channels | Tuning while tethered |
| **3. Post-processing** | MCAP → Foxglove | offline | Synchronised replay, jump-by-jump comparison |

### 1.1 Onboard binary logger

~60 channels × 4 bytes at 1 kHz = **~240 kB/s**, ~14 MB per minute. A class-10
card does this comfortably; the failure mode is not throughput, it is **write
latency spikes** when the card does internal wear levelling.

Rules that make it work:

- **Preallocate with `f_expand()`** so the file is contiguous — this removes
  FAT-chain updates from the write path, and it is the single biggest win.
- **Lock-free SPSC ring buffer** filled by the 200 Hz logger task, drained in
  **4 kB blocks** by a low-priority writer task. Never write from the ISR.
- **Never block the control ISR on the card.** If the ring overflows, drop
  frames and increment a counter — a dropped log line is survivable, a missed
  control tick is not.
- **Fixed-width binary frames with a magic word and a sequence number**, not
  CSV. CSV formatting costs more CPU than the write.
- **Flush and close on fault latch**, and on the e-stop path. A log that ends
  10 ms before the interesting event is worthless.

Channel set: `t_us`, θ, θ̇, θ̂, gyro/accel raw ×6, φ_L/φ_R and rates,
θ_s_L/θ_s_R and rates, wheel positions/velocities, all four commanded and
measured torques, bus V and I, per-cell V, FSM state, fault word, CAN error
counters per bus, ISR execution time, loop-latency timestamp pair.

### 1.2 Live telemetry

PlotJuggler over UDP with a plain JSON or protobuf payload, 100–200 Hz,
decimated and **droppable** — the transmit task is the lowest priority in the
system and must never apply backpressure to anything.

### 1.3 Post-processing

Write an MCAP converter for the binary format once, early. Foxglove then gives
you synchronised multi-channel replay and lets you overlay two jumps. Budget
half a day; it pays for itself on the first tuning session.

## 2. Bring-up plan

**No stage starts until the previous stage's gate is green.** Every stage runs
on the stand until Stage 4.

> **Active ABS single-leg carve-out, owner decision 2026-09-02.** Complete the
> whole single-leg integration article in ABS before committing to PA-CF. Stage
> 0 and Stage 1 run as written. For Stage 2, communicate with each actuator first
> on the bench with its output free, then on the assembled leg with the wheel
> clear, the supply and drive current-limited, and no load beyond self-weight.
> Confirm identity, direction, encoder/telemetry, stop behaviour, logging,
> phase resistance, loop latency, the unloaded CAN soak, and short slow-motion
> commands. Do **not** run the lever/scale torque sweep, preload
> the main spring, characterize the spring, apply ground traction, command stall,
> or use the ABS stand as a measurement fixture. Those gates move to the later
> two-leg PA-CF structural build. Stage 3 and beyond remain deferred.

Build the stand first: a rigid frame that holds the shoulder axis with wheels
clear of the ground, plus a **pitch-only gimbal** mode where the robot can
rotate freely in pitch but cannot fall over or travel. Most of Stage 3 lives on
that gimbal.

### Stage 0 — Bench, no motors

| | |
|---|---|
| **Do** | Power the main board from a **current-limited bench supply at 0.5 A**, never the pack. Bring up SWD, clocks, the three FDCAN peripherals in loopback, IMU SPI, SD card, telemetry. **Single-leg rig: use the Teensy 4.1 — bring up two CAN buses (500 kbps), IMU SPI, and the onboard microSD.** |
| **Gate** | All three CAN peripherals pass loopback. SD writes 240 kB/s sustained for 10 minutes with zero dropped frames. ~~IMU streams at 8 kHz.~~ **Single-leg rig Mode A: two CAN buses, and the IMU gate is 1 kHz raw, not 8 kHz** — the on-hand BNO085 cannot stream faster (SH-2 raw gyro ~1 kHz; calibrated/uncalibrated gyro 100 Hz). The 8 kHz gate applies to the two-leg robot's ICM-42688-P. |
| **Trap** | If SD throughput is marginal here it will be catastrophic under load. Fix it now. **And read the BNO085 raw** — its on-chip fused output carries 6.6 ms of latency, which by itself exceeds most of Stage 2's <8 ms budget (`03_compute_and_can.md` §4). |

### Stage 1 — Estimator, no motors

| | |
|---|---|
| **Do** | Run the full 2-state KF. Hand-rotate the robot against a printed protractor. Verify the accelerometer-tilt correction (`04_firmware.md` §5.1) by shaking the chassis horizontally — a naive estimator shows tilt, a correct one does not. |
| **Gate** | **Static pitch bias <0.1°, noise <0.05° RMS, no drift over 10 minutes.** Gyro bias converges within 10 s of boot. |
| **Trap** | Do not proceed with a "good enough" estimator. A 1° bias is 0.92 m/s² of commanded acceleration — you will chase it as a control bug for a week. |

### Stage 2 — One actuator, free shaft, and the latency measurement

| | |
|---|---|
| **Do** | **Active ABS article:** one actuator on the bench with output free, then both actuators on the complete leg with the wheel clear; use current limits and short slow commands to verify identity, direction, encoder/telemetry, stop behaviour and logging. Measure phase R with a milliohm meter (C7), measure end-to-end loop latency by toggling GPIO at IMU-sample-complete and torque-written-to-mailbox, and run the unloaded CAN soak. **Deferred two-leg structural gate:** sweep 0.1 → 5 N·m against a lever arm and kitchen scale. |
| **Gate** | **Active ABS article:** correct identity/direction, prompt zero command and stop response, coherent telemetry/logs, end-to-end latency <8 ms, and no CAN errors in a 1-hour soak at 1 kHz without externally loading the leg. **Deferred two-leg structural gate:** measured torque within 20% of `Kt × I`. |
| **Trap** | Nothing downstream matters if latency fails. Published bench tests found 4.8–9.4 N·m against an 11 N·m rating; if you measure below 5.9 N·m, the jump spec changes here, not after the PCB order. |

### Stage 3 — Balance on the gimbal

| | |
|---|---|
| **Do** | Full four-actuator bus, robot on the pitch gimbal. Start with the **very-soft** gains `[−0.500, −1.422, −7.592, −0.855]` (20 ms margin), then the soft set. Add the ∫θ state. Verify the wheel-odometry shank term with the chock test (`04_firmware.md` §5.2). |
| **Gate** | Holds pitch within ±2° against a hand push, recovers in <1 s, **no growing 3–4 Hz oscillation**, no CAN faults. Latency still <8 ms with all four nodes live. |
| **Trap** | **This is where the 3.66 Hz bounce mode shows up.** If pitch oscillation grows as you raise K_θ, that is the mode, not a gain problem. Turn on shoulder damping injection (`c_φ ≈ 0.19 N·m·s/rad`) and bias the stance to θ_s ≈ ±12° so the shoulders have authority. |

### Stage 4 — Free balancing

| | |
|---|---|
| **Do** | Off the stand, tether from above, foam mat, **helmet on the IMU end** — a fall onto the datum pad ruins the calibration. Zero velocity command first, then rate-limited velocity to 0.5 m/s. |
| **Gate** | 5 minutes standing without intervention. Drives 2 m and stops. **Peak current logged and compared against `01_power_and_battery.md` — this is where the estimated power budget gets replaced with measurements.** |
| **Trap** | Rate-limit the operator velocity command to ~0.5 Hz. The RHP zero at +6.53 rad/s means a step velocity command makes the robot go backwards first; an operator who fights that will drive it into the floor. |

### Stage 5 — Drop tests, unpowered then powered

> **Single-leg rig: [DEFERRED — MODE B] (2026-08-17).** The rig build is Mode A
> only — no vertical slide, no drop release, and **no brake chopper to sink the
> regen a drop produces**. Rig steps 10–11 are not run. This stage still applies in
> full to the **two-leg robot**, which now inherits the drop question unmeasured;
> see `beni_single_leg_rig_design_record.md` §11. ⚠ **Do not improvise a drop test
> by hand on the Mode A stand** — the gate below exists because an over-height drop
> is how the knee gets destroyed, and the chopper is not built.

| | |
|---|---|
| **Do** | Drop from a hoist, shoulders held at a fixed extended pose, **starting at 20 mm** and increasing in 10 mm steps. Log φ peak on every drop and plot φ_peak vs drop height. Then repeat with the landing impedance controller live. |
| **Gate** | **The brief's gate — "no powered jump until a 100 mm drop never reaches +27°" — cannot be passed passively.** Passive capacity is ~49 mm on the two-leg robot's 1-DOF model (`fusion_brief_single_leg_rig.md` §4.3); the single-leg rig's 2-DOF integration puts the +24° crossing at **46.3 mm**, so the planning limit is **45 mm** (`beni_single_leg_rig_design_record.md` §3). Replace it with: **(a) a 45 mm free drop never exceeds +24° passively, and (b) a 100 mm drop never exceeds +24° with the shoulder landing controller active.** |
| **Trap** | Extrapolate the φ_peak curve before each step up. If the trend line hits +24° at 40 mm, do not "just try" 50 mm. Use the measured curve to set `A_MAX` in the CBF. **Never extrapolate past the last measured point.** |

### Stage 6 — Jumping

| | |
|---|---|
| **Do** | Tethered from above, over a mat. **Scissor crouch** (L = +θ, R = −θ). Ramp thrust torque in 10% increments from a 20% baseline. Log takeoff θ̇ every attempt. |
| **Gate** | Repeatable hop with **takeoff \|θ̇\| < 1 rad/s** and a landing that recovers to BALANCE without hitting the hard stop. Then remove the tether. |
| **Trap** | Angular momentum is conserved in flight — you cannot fix a bad takeoff. If takeoff θ̇ is high, fix the crouch symmetry and the thrust ramp; do not add flight-phase gain. |

## 3. Cross-cutting rules

- **Torque mode always.** Never the drive's internal position mode past Stage 2.
- **Every stage runs with logging on.** A test you did not log is a test you did
  not run.
- **Version the log format** with a header word, and commit the parser alongside
  the firmware. A month of logs you can no longer decode is a real failure mode.
- **Re-run Stage 1's estimator gate after any fall** onto the IMU end.
- **Test-jump at ≤4.1 V/cell**, never straight off the charger — regen has
  nowhere to go at full charge (`01_power_and_battery.md` §7.2).
- Keep the **loop key** within reach at every stage from 3 onward, and keep the
  robot on a mat.

## 4. Schedule

| Stage | Elapsed | Notes |
|---|---|---|
| 0–1 | 1–2 weeks | Can start on a dev board before the PCB arrives |
| 2 | 3–5 days | Blocked on actuators in hand |
| 3 | 1–2 weeks | The bounce mode may eat a week on its own |
| 4 | 3–5 days | |
| 5 | 1 week | Slow by design — 10 mm steps |
| 6 | 2+ weeks | Open-ended |

Runs concurrently with a **4–6 week PCB lead time** (`03_compute_and_can.md`
§3), so Stages 0–1 should be done on the WeAct fallback board while the custom
board is in fab. **For the single-leg rig, use the Teensy 4.1** — no PCB lead
time, no fallback needed.

**Current mapping (owner decision 2026-09-02).** The ABS single-leg programme
runs Stages 0–1 and the unloaded/current-limited integration, resistance,
latency and CAN-soak subset of Stage 2 above. The lever torque sweep and rig step 6 spring characterisation are now
deferred with PA-CF to the later two-leg structural build. Stages 3–6 and rig
steps 7–11 remain deferred as before.

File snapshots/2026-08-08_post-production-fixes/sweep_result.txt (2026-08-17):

  theta=   +0 phi=  -8   real clashes: 0   bumper crush 1.4 mm3
  theta=   +0 phi=  -6   real clashes: 0
  theta=   +0 phi=  +0   real clashes: 0
  theta=   +0 phi=  +5   real clashes: 0
  theta=   +0 phi= +10   real clashes: 0
  theta=   +0 phi= +15   real clashes: 0
  theta=   +0 phi= +20   real clashes: 0
  theta=   +0 phi= +22   real clashes: 0   bumper crush 2.4 mm3
  theta=   +0 phi= +25   real clashes: 0   bumper crush 8.6 mm3
  theta=   +0 phi= +27   real clashes: 0   bumper crush 12.7 mm3
  theta= -185 phi=  +0   real clashes: 0
  theta= -120 phi=  +0   real clashes: 0
  theta=  -60 phi=  +0   real clashes: 0
  theta=  +30 phi=  +0   real clashes: 0
  theta=  +60 phi=  +0   real clashes: 0
  theta= +120 phi=  +0   real clashes: 0
  theta= +185 phi=  +0   real clashes: 0
  theta=  -35 phi= +12   real clashes: 0
  theta= -185 phi=  -8   real clashes: 0   bumper crush 1.4 mm3
  theta= -185 phi= +27   real clashes: 0   bumper crush 12.7 mm3
  theta= +185 phi=  -8   real clashes: 0   bumper crush 1.4 mm3
  theta= +185 phi= +27   real clashes: 0   bumper crush 12.7 mm3

  NO GENUINE INTERFERENCES across 22 poses

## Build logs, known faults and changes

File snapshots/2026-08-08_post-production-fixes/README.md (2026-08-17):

# REV2 SNAPSHOT — 2026-08-08, after production-readiness fixes

State of `Biped → Beni_Prototype1` and this folder after the fix programme in
`beni_prototype1_rev2_changes.md`.

Compare against `../2026-08-08_pre-production-fixes/`.

| file | what it is |
|---|---|
| `Beni_Prototype1_REV2.f3d` | full parametric Fusion archive, 5.0 MB |
| `Beni_Prototype1_REV2.step` | neutral B-Rep of the whole assembly, 7.4 MB |
| `rev2_metrics.json` | every occurrence + component: volume, face/edge/shell/lump counts, transform, **material**, appearance, cylindrical-face radius census, plus assembly mass / CoM / inertia and all 36 user parameters |
| `beni_lib.py`, `beni_export.py` | build + export source |
| `*.md` | all five documents |
| `manufacturing/` | 10 machined-part STEPs + the spec sheet |
| `sim/` | URDF + inertia JSON |
| `print_stl_REV2/` | re-exported print set |

A named Fusion **cloud version** was created at the same moment:
> "REV2 2026-08-08: production-readiness fixes -- L/R parity restored, fastener defects fixed, fillets added, tyre retention, chassis builders, physical materials + true mass properties."

## Headline deltas vs baseline

| | baseline | REV2 |
|---|---:|---:|
| Fusion-reported mass | 8174.2 g | **3290.1 g** |
| CoM known? | no | **yes** — X +6.46, Y −0.00, Z −50.57 mm |
| Inertia tensor known? | no | **yes** — Iyy 0.02508 kg·m² |
| Fillets | 0 | **41** |
| Right-leg parts missing | 3 | **0** |
| Unfittable fastener sets | 1 | **0** |
| Screws bottoming out | 2 joints | **0** |
| Parts with no builder | 4 | **0** |
| Machined-part STEP / drawings | none | **10 STEP + spec sheet** |
| URDF | none | **6-link, mass closure exact** |
| Automated audit problems | (no harness) | **0 of 5 checks** |

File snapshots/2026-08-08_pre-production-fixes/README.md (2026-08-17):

# BASELINE SNAPSHOT — 2026-08-08, before production-readiness fixes

State of `Biped → Beni_Prototype1` and this folder immediately before the
Tier 0–3 fix programme described in
`beni_prototype1_production_readiness_findings.md`.

| file | what it is | how to restore |
|---|---|---|
| `Beni_Prototype1_BASELINE.f3d` | full parametric Fusion archive, 4.5 MB | Fusion → Upload, or File → Open, then Save As over the working doc |
| `Beni_Prototype1_BASELINE.step` | neutral B-Rep of the whole assembly, 7.2 MB | opens in anything; geometry only, no timeline |
| `baseline_metrics.json` | every occurrence + component: volume, face/edge/shell/lump counts, bbox, 4×4 transform, material, appearance, cylindrical-face radius census, all 31 user parameters | diff target — `compare_to_baseline.py` uses this |
| `beni_lib.py` | build source as it stood | — |
| `*.md` | all four documents as they stood | — |
| `print_stl_BASELINE/` | the exported STL set as it stood | — |

A named Fusion **cloud version** was also created at the same moment:
> "BASELINE 2026-08-08: state before production-readiness fixes (audit findings doc). Restore point."

Recover it from the Fusion data panel → `Beni_Prototype1` → right-click → Versions.

## Baseline facts, for quick reference

- timeline 815 entries · 156 root occurrences · 79 components · 31 user parameters
- 0 joints, 0 as-built joints, 0 rigid groups, 0 snapshots, 0 named views
- 217 extrudes, 11 revolves, 1 mirror, **0 fillets, 0 chamfers**
- all bodies mis-assigned material "Steel" → Fusion reported mass 8174.2 g
- corrected mass (by hand) 3232.2 g modelled, ≈3352 g with unmodelled electronics
- right leg missing `Knee_Axle_L`, `Knee_Sleeve_L`, `Knee_Spring_L` entirely
- `Proximal_Link_L(Mirror)` 70356.44 mm³ vs left 63093.07 mm³
- `Knee_Encoder_Bracket_L(Mirror)` 2726.12 mm³ vs left 2614.88 mm³

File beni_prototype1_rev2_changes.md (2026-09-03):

# Beni Prototype 1 — Revision 2 Change Record

> **Later note, 2026-08-12.** Revision 2 added
> `archive/manufacturing/machined_parts_spec.md` and the per-part STEP exports to close
> finding 3.9. The build has since moved to **3D printed and off-the-shelf parts
> only, with no laser cutting or machining** —
> [`MANUFACTURING_CONSTRAINTS.md`](MANUFACTURING_CONSTRAINTS.md) — so those
> outputs are now a tolerance reference rather than a shop package. Nothing else
> in this changelog is affected.

**Date:** 2026-08-08
**Scope:** Close the defects and production gaps identified in
[`archive/prototype1_production_readiness_audit.md`](archive/prototype1_production_readiness_audit.md).
**Baseline:** `snapshots/2026-08-08_pre-production-fixes/` (f3d + STEP +
metrics JSON + a named Fusion cloud version).
**Result:** `snapshots/2026-08-08_post-production-fixes/` (same set, REV2).

Everything below was verified by measurement out of the model, not by
inspection. The automated audit is `beni_lib.audit_all()`.

---

## 1. Status of every finding

| # | Finding | Status |
|---|---|---|
| 3.1 | No physical materials; no CoM or inertia | **Fixed** — §2 |
| 3.2 | Right leg an incomplete copy (3 parts missing, 2 stale) | **Fixed** — §3 |
| 3.3 | Three knee-stop screw heads physically collide | **Fixed** — §4 |
| 3.4 | Blind insert bores too shallow; screws bottom out | **Fixed** — §4 |
| 3.5 | `build_all()` would break the model | **Fixed** — §5 |
| 3.6 | Zero fillets in the whole design | **Fixed** — §6 |
| 3.7 | Tyre has no retention and no crown | **Fixed** — §7 |
| 3.8 | Interference audit hid three real defects behind a screw filter | **Fixed** — §8 |
| 3.9 | No STEP, no drawings, no tolerances for machined parts | **Fixed** — §9 |
| 3.10 | Electronics and harness are placeholders; no IMU datum | **Partly fixed** — §10 |
| 3.11 | Actuator sizing never checked against the duty cycle | **Quantified, not closed** — §11 |
| 3.12 | Items blocked on outside information | **Still open** — §11 |
| Tier 3 | Live Fusion joints | **Deliberately not done** — §12 |

**Audit result after the work:**

```
COUNTS:                  clean (72 part/side entries, 1 body each)
L/R PARITY:              clean (32 part families matched)
FASTENER HEAD CLEARANCE: clean
BLIND HOLES:             clean
SOURCE PARITY:           36 parts in model, 36 classified
TOTAL PROBLEMS:          0
```

Interference: 72 pairs, of which **70 are screw-shank-in-tap-drill modelling
artifacts** and 2 are the documented M4-stud-in-tap-drill artifact at the magnet
carrier. No structural clashes.

**Motion sweep, 22 poses** (`beni_lib.sweep_check()` — full knee range at the
shoulder nominal, full shoulder range at the knee nominal, and all four
knee/shoulder corners): **no genuine interferences.** Bumper crush reproduces
the revision-1 verified table exactly — 1.4 mm³ at φ = −8 on the extension pad,
then 2.4 / 8.6 / 12.7 mm³ on the flexion pad at φ = +22 / +25 / +27.

Kinematics re-verified after the full rebuild: the wheel axis matches the
closed-form solution to **0.0000 mm** at θ/φ = (0,0), (0,+25), (0,−8),
(−35,+12) and (+185,0).

---

## 2. Mass properties — the model now knows what it weighs

Every body carried the default "Steel". Fusion reported **8174.2 g**.

Fixed by `beni_lib.apply_materials()`, which creates design-local materials with
the right density per material class, and derives a density from the modelled
volume for the four bodies that are **envelopes rather than solids** (the spring,
the harness spiral, the battery and the electronics block).

| | before | after |
|---|---:|---:|
| Mass reported by Fusion | 8174.2 g | **3290.1 g** |
| CoM X (fore-aft) | — | **+6.46 mm** |
| CoM Y (lateral) | — | **−0.00 mm** |
| CoM height above the wheel axis | — | **103.7 mm** |
| Iyy about CoM (pitch) | — | **0.02508 kg·m²** |
| Ixx / Izz about CoM | — | 0.03214 / 0.01706 kg·m² |
| Ixz about CoM | — | +0.002759 kg·m² |
| Inverted-pendulum τ = √(L/g) | — | 0.103 s |

3290.1 g against the BOM's previous hand estimate of 3304 g, so the old
arithmetic was sound — but it lived in a markdown table, not in the model, and
there was no CoM or inertia anywhere.

**CoM Y = −0.00 mm is now a standing symmetry check.** Any part missing from one
leg shows up here immediately; it is how the missing right-hand spring in §3 was
caught after the first repair pass.

**Fore-aft offset.** The battery moved aft (centre X = −0.5 → −30.5) and the
electronics block was placed at X = −52, taking the offset from **+11.97 mm to
+6.46 mm**. It does not go to zero, and chasing it further is not worth doing:
the offset is inherent to the bent-leg geometry — the two links and the knee
hardware sit around X = +45…+92 while both wheels and both shoulder motors sit
at X = 0 — and nulling it would need ~89 mm of travel on the entire 450 g
chassis group, which does not exist in a 110 mm frame.

What that means for controls, stated plainly: the residual is a **0.21 N·m
standing bias** (0.11 N·m per wheel, trivial for the wheel actuators), and the
**equilibrium stance is a few degrees off the nominal pose** rather than exactly
on it. That is a trim term, not a defect.

Per-link masses and full inertia tensors: `sim/beni.urdf`,
`sim/beni_inertia.json`.

---

## 3. The right leg is now structurally incapable of diverging

**What was wrong.** The entire right leg came from a single `MirrorFeature`
taken early. Fusion's mirror-to-new-component is not associative, so every
left-leg edit after that point was invisible to the right leg:

- `Knee_Axle_L`, `Knee_Sleeve_L`, `Knee_Spring_L` did not exist on the right at
  all — the right knee had no axle, no sleeve and no spring;
- `Proximal_Link_L(Mirror)` was 7263.36 mm³ heavier, exactly π·17²·8, the volume
  of the Ø34 hub-access bore. The six shoulder output-hub screws were
  unreachable on the right leg;
- `Knee_Encoder_Bracket_L(Mirror)` was missing the three Ø5 driver-clearance
  holes, so the right leg's knee-stop screws were covered by the bracket shelf.

**Fix.** `beni_lib.build_mirror()` drops the old mirror and rebuilds it from the
finished left leg, and it is now the last step of every rebuild. The failure
mode was not "the mirror was wrong", it was "the mirror was taken once" — so the
fix has to be procedural, not a one-time repair.

**Second-order bug found while verifying this.** `rebuild_spring()` is called by
`set_pose()`, and it only built the left spring. So merely *posing* the model
deleted the right leg's spring and re-created the left one as default steel
(51 g instead of 25.3 g). Posing the assembly silently corrupted it. Fixed:
`rebuild_spring()` now owns **both** springs and re-applies the material, and
`Knee_Spring_L` is excluded from the mirror. Verified by a pose round-trip.

**Third bug found the same way.** `drop_comp()` deleted only the *first*
matching occurrence, which made every builder non-idempotent in two compounding
ways — placements accumulated (57 M3 × 10 screws instead of 14 after one extra
build) and, because `new_comp()` reuses a surviving component, a second call
appended a whole new body to it (the 6800 bearing became four stacked copies of
itself). `drop_comp()` now clears the component completely, and
`audit_counts()` checks both occurrence counts and one-body-per-component.

**Fourth bug, introduced by the fix to the second and caught by the motion
sweep.** Making `rebuild_spring()` build both springs at the *same* knee angle
was wrong: mirrored occurrences are treated as STATIC by `classify()`, so during
a left-leg sweep the right leg stays at nominal, and a right spring built for the
left leg's knee angle is the wrong length for the un-posed right cartridge. It
read as ~320 mm³ of interference on the right leg at every φ ≠ 0.
`rebuild_spring(phi, phi_mirror=0.0)` now takes the two angles separately.

This one is worth recording for a second reason: the interference report labelled
the clashes `Cart_Lower_Eye_L ↔ Knee_Spring_L(Mirror)`, which looks impossible
because those parts are 150 mm apart in Y. Fusion reports a mirrored occurrence
under its **source occurrence's `name`** while the *component* carries the
`(Mirror)` suffix, so the pair looked like a left-vs-right collision. The only
way to tell was to read the bounding box of the interference body itself — all
of it was at negative Y. Trust the clash volume's location, not the names.

`beni_lib.sweep_check()` now classifies known artifacts and designed contact
(bumper crush) so this class of confusion does not have to be re-litigated:
it prints real clashes only, and reports bumper crush as a positive result.

---

## 4. Fastener defects

### 4.1 Knee-stop screw heads (the crash load path)

`STOP_BOLT_A` was `(240°, 260°, 280°)` on a 15 mm radius. Centre-to-centre
2 × 15 × sin(10°) = **5.209 mm** against a **Ø5.5** M3 SHCS head: the three
heads overlapped by 0.29 mm and **could not all be fitted**. Confirmed by
interference at 1.03 mm³ per pair, which matches the closed-form lens area
exactly.

Now `(230°, 260°, 290°)` — 30° spacing, **7.765 mm** centres, 2.27 mm of gap
between heads and room for a 2.5 mm hex key on each. The arc plate grew 12° of
sector to carry the wider pattern (+2.3 g each, 2164 → 2463 mm³).

This is the fastener set that takes the entire hard-stop impact — 534 N at
r = 30 mm (214 N static × 2.5). The original driver-access audit modelled 32
hex-key envelopes and passed, because it only ever asked whether a tool could
reach a screw, never whether two screws could coexist.

### 4.2 Blind insert bores

Both blind-insert joints were wrong the same way: the bore was shallower than
the 5 mm insert, and the screw ran past the bore floor.

| joint | bore was | bore now | screw was | screw now | clearance now |
|---|---:|---:|---|---|---:|
| knee stop arc → arm B | 4.50 | **5.00** | M3 × 8 | **M3 × 6** | +2.00 mm |
| cable cover → inserts **[REV2 history; superseded 2026-09-02]** | 4.00 | **5.00** | M3 × 10 | **M3 × 8** | +2.00 mm |
| encoder bracket → arm B | 5.00 | 5.00 | M3 × 16 | M3 × 16 | +0.60 mm |

Arm B is only 5.8 mm thick at the boss, so 5.00 mm is the deepest bore that
leaves a floor (0.80 mm). That constrains the screw to M3 × 6, giving 3.0 mm of
thread into the insert — 1.0 × d, acceptable **because this joint is loaded in
shear, not pull-out**, which the design record already establishes.

Build note: the 0.80 mm blind floor means the inserts must go in with a
depth-stopped tip. Same floor as the encoder-bracket inserts, which were already
at that depth.

> **Current disposition, 2026-09-02:** the cable-cover row above records the
> revision-2 repair but is no longer the released joint. A complete-assembly
> audit showed its inboard screw heads colliding with the stand/chassis volume.
> The cover now has Ø3.4 clearance holes, four 5 mm M3 inserts live through the
> shoulder plate, and M3 × 10 screws enter from the accessible outboard face
> with 1.5 mm tip clearance.

Both checks are now automated: `audit_fasteners()` (head-to-head clearance for
every screw pair sharing a seat plane) and `audit_blind_holes()` (bore depth vs
insert length vs screw reach).

---

## 5. `beni_lib.py` now actually reproduces the model

`build_all()` did not rebuild every part, and running it would have **silently
destroyed the chassis joint**:

- no builder existed for `Chassis_Frame`, `Electronics_Tray`, `Battery_4S2200`
  or `Shoulder_Cable_Spiral_L`;
- `build_shoulder_plate()` had drifted to a much older revision of the panel. The
  model's panel is a **rectangular lightened side panel** (−72…+42 × −24…+72,
  four lightening windows, six chassis-mount holes) with a Ø96 lobe around the
  motor. The builder made a bare Ø96 disc with no chassis holes at all.

So `build_all()` would have dropped the panel, rebuilt it without the
panel-to-frame bolt pattern, and left the frame orphaned with ten unmatched
holes — and the result would have looked fine.

All five builders were written from geometry reverse-engineered out of the
timeline, `build_all()` now ends with `add_fillets()`, and
`audit_source_parity()` checks that every modelled part has a class and vice
versa. `FRAME_BOLTS` is the single source of truth for the joint, shared by the
panel and the frame builders.

**One deliberate deletion.** The panel carried a sixth chassis hole at
(X = +30, Z = −18) with no matching boss on the frame. Giving the frame a
front-lower leg to reach it costs 19–29 g against a 210 g margin, and the
pattern is nowhere near load-limited — at the 25 N·m proof torque the worst of
the five bolts sees **82 N**. The orphan hole is deleted instead.

Also removed: the dead `HW_SHCS_M3x14` / `M4x14` entries in `PART_CLASS`, the
stale `ENC_PCB_Y` constant, and the `Chassis_Deck_Top/Bottom` placeholders that
were never modelled.

---

## 6. Fillets

The design had **0 fillet features in 815 timeline entries** — 217 sharp-cornered
extrusions. For FDM PA-CF under impact this was the single highest-return
structural change available, because printed parts crack at sharp re-entrant
corners long before the nominal section stress is reached.

**41 fillets added** by `beni_lib.add_fillets()`, which selects edges
geometrically (Y-parallel line edges of a known length for cut corners, circular
edges of a known radius and Y for boss roots) and fillets **per edge**, so a
single edge that cannot take the radius does not abort the set.

| Part | Location | Radius |
|---|---|---|
| `Proximal_Link_L` | 20 mm spring-channel corners | R2.5 → R1.0 |
| `Proximal_Link_L` | root-pad step (Ø62 disc, the M4 root-bolt clamp face) | R2.0 |
| `Proximal_Link_L` | both knee bearing-boss roots (0.8 mm steps) | R0.5 |
| `Distal_Link_L` | channel corners | R2.5 → R1.0 |
| `Distal_Link_L` | wheel-end plate root (8 mm plate off the 5 mm arm) | R2.0 |
| `Distal_Link_L` | knee boss ends (Ø16 sleeve press fit) | R1.5 |
| `Chassis_Shoulder_Plate_L` | lightening-window corners | R2.0 |
| `Chassis_Frame` | web corners | R2.0 |

Net effect on mass is small and in the right direction: proximal link
−66.65 mm³, distal link −2.99, frame −288.42.

---

## 7. Tyre and rim

As modelled the tyre was a **4-face plain annulus** whose ID (Ø96) exactly
equalled the rim seat OD. No press fit, no bead, no lip, no crown — a smooth TPU
ring on a smooth PA-CF drum that would spin under braking and walk off inboard.

Three real features added:

1. **Bead groove + rib.** Groove cut into the drum at r = 46.5 → 48 over
   y = 82.5…85.5 (centred on the tyre centre plane), with a matching internal rib
   on the tyre. Locks the tyre axially and in torsion without relying on friction.
2. **Inboard flange** on the rim, r = 48 → 52 over y = 68…69. It has to live
   outboard of y = 67.5, because that is where the distal link's Ø112 relief
   starts — inboard of it the fork arms are still full section out to r ≈ 84 from
   the wheel axis. The drum was extended inboard to y = 68 so the flange shares
   the Ø96 face rather than meeting it on an edge, which would be non-manifold.
3. **Crowned tread**, a true R150.4 torus dropping 0.75 mm from Ø110 at the
   centre plane to Ø108.5 at each edge.

The tyre stays **modelled at ID Ø96 in its installed state** so it does not read
as a permanent 8000 mm³ interference in every future audit; the **free ID is
Ø94** and that is what the BOM orders. Mass is essentially unchanged (81.5 →
80.1 g each) for three functional gains.

Implementation note: this needed a revolve about a Y axis, which the library had
no way to do — every sketch helper was Y-normal. `sk_axial_y()` / `rev_profile()`
were added, mapping points through `modelToSketchSpace` rather than assuming a
sketch orientation, and using an in-sketch construction line as the axis because
`constructionAxes.add()` raises "Environment is not supported" from a script.

---

## 8. The audit harness now catches what it missed

The original interference audit was run with screws filtered out — and §4.1 and
§4.2 were both sitting in the screw-versus-part results. Four checks added to
`beni_lib`, each because its absence let a real defect through:

| Check | Catches |
|---|---|
| `audit_counts()` | duplicate occurrences, components with more than one body |
| `audit_lr_parity()` | any L/R divergence, by per-part volume and face census |
| `audit_fasteners()` | screw heads that overlap each other |
| `audit_blind_holes()` | bore depth vs insert length vs screw reach |
| `audit_source_parity()` | modelled parts with no builder or no material class |

`audit_all()` runs the set and prints a problem count. It reports **0**.

---

## 9. Manufacturing outputs

- **`archive/manufacturing/step/*.step`** — one STEP AP214 per machined part family, all
  ten. A shop could not previously quote or program anything, because STL was the
  only output.
- **`archive/manufacturing/machined_parts_spec.md`** — fits, tolerances, surface finish,
  hardness and handedness for all ten, with the H7/H8/h6/n6 classes actually
  called out instead of described in prose. Includes the hardness spec on
  `Knee_Stop_Arc_L` (45 HRC through, or 50–55 HRC cased at the slot ends) that
  the BOM previously left as the word "hardened" on the final crash surface.
- **`print_stl/`** re-exported from the corrected model, including the eight
  PLA check-prints of the metal parts. The `GAUGE_*` motor stand-ins are
  untouched — they live in `Beni_Prototype1_TestGauges` and nothing here affects
  them.
- **`web/`** viewer regenerated, 27 meshes, 147 350 triangles, 0.96 MB. The
  manifest is now derived from `beni_lib.classify()` and `PART_CLASS` instead of
  being hand-maintained, so it cannot drift from the model. `web/check.py`
  passes: 81/81 poses, all seven kinematic groups present.

---

## 10. Electronics — modelled, not yet designed

`Chassis_Electronics` now exists: a 120 g block at X = −61.5…−44, Z = 0…41.5,
Y = ±25, carrying a **12 × 12 mm IMU datum pad** standing 1.5 mm proud of its
top face with its axes aligned to the robot frame. That pad is the reference the
CoM and inertia in §2 are stated against, so it needs to be a real face in the
model rather than a note.

It has to sit **aft of the shoulder motors**: both motors are Ø80 cylinders about
the Y axis spanning |y| = 5…49, so the whole region r < 40 from the shoulder axis
is motor territory at every y. The first placement attempt put the block inside
both motors (1019 mm³ of interference) and its IMU pad inside the battery —
caught by the interference re-run, not by eye.

Clearances as built: 4.00 mm to the shoulder motor, 0.50 mm to the battery.

**Still a placeholder, not a design.** There is no board outline, no connector
placement, no CAN routing or termination, no power distribution, no e-stop, no
charge port and no chassis skin. What has changed is that the 120 g now has a
location, so the mass properties are real.

**Encoder air gap — documentation was wrong, geometry was fine.** Measured:
magnet face at y = 96.30, sensor package face at 97.30, so **1.00 mm of
mechanical clearance**. The AS5048A is a TSSOP-14 about 1.0 mm thick with the die
near mid-package, so the **magnet-to-die gap is ≈1.5 mm** — inside the AMS
operating window for a Ø6 × 2.5 diametric magnet. The design record's "1.00 mm
air gap" was measuring to the package face, not the die. No geometry changed;
the claim is now stated correctly.

---

## 11. Still open

**Actuator sizing (quantified here for the first time).** The structure is
proof-designed to 25 N·m at the shoulder, which is conservative and right. But
nobody had checked whether the motor can produce the motion the design depends
on:

| case | required per leg | GIM6010-8 |
|---|---:|---|
| hold the leg statically | 0.49 N·m | trivial |
| **drive a 3 g jump through the leg (lever ≈120 mm)** | **≈5.9 N·m** | ~4.6–5.4 N·m **rated**, 11–17.9 N·m stall |

The jump — the entire point of the passive knee — sits **at or just above
continuous rated torque** and depends on peak capability. Probably fine for a
short impulse, but it is the design's central assumption and it is unverified.
It also promotes the exact-variant question from a footnote to a gating item.

Wheel side is comfortable: 0.09 N·m to accelerate at 1 m/s², 0.11 N·m to hold
the residual CoM offset, 0.23 N·m on a 15° slope.

**Landing energy, recomputed.** The two knees absorb **1.776 J each, 3.553 J for
the pair**, φ = 0 → +27° (numerically integrated). A 100 mm free drop at the
corrected 3.29 kg mass carries **3.227 J**, so there is now **+10 % margin**
rather than the ≈0 % the design record recorded against 3.5 kg. The conclusion
is unchanged: the shoulder must participate.

**Blocked on suppliers, unchanged:** exact GIM6010-8 variant / bus voltage /
driver firmware / CAN and encoder configuration; spring rate tolerance and
achieved solid height (only 4.89 mm of margin at the +27° stop); PU bumper
compound (49 % crush is at the top of sensible); PA-CF print parameters.

---

## 12. Live Fusion joints — deliberately not added

The findings document listed real joints with limits as Tier 3, to make the model
movable by someone without `beni_lib.py`. **I did not add them, and the reason is
that they would break something load-bearing.**

Posing in this project is done by writing occurrence transforms
(`beni_lib.set_pose()`), and that mechanism is what every collision sweep,
clearance table and kinematic verification in the design record runs on. Fusion
joints constrain occurrence transforms, so live joints and scripted posing cannot
coexist — adding joints would have traded a verified 0.0000 mm-accurate
verification harness for the ability to drag the model by hand.

The need is already met from two directions:

- **`sim/beni.urdf`** carries the real kinematic tree with mechanical limits
  (shoulder ±185°, knee −8°…+27°, wheel continuous) and true inertias. That is
  the handoff that actually matters, and it is machine-readable.
- **`web/index.html`** already provides interactive posing with correct
  kinematics for anyone who does not have Fusion at all.

What was added instead: the limits are now **Fusion user parameters**
(`joint_shoulder_min/max`, `joint_knee_min/max`, `joint_knee_bumper`) so they are
visible in the CAD parameter table rather than living only in convention.

If live joints are wanted later, the right move is a separate derived document,
not the master assembly.

---

## 13. What changed in the source

| File | Change |
|---|---|
| `beni_lib.py` | 1742 → ~2790 lines. Fixed `drop_comp` idempotency; added `find_all_occ`, `sk_axial_y`, `rev_profile`, `add_fillets` + edge selectors, `build_chassis_frame`, `build_electronics_tray`, `build_battery`, `build_electronics_block`, `build_cable_spiral`, `build_mirror`, `drop_mirror`, `apply_materials`, `mass_report`, `mass_by_part`, and the five `audit_*` functions. Rewrote `build_shoulder_plate`, `build_wheel`, `rebuild_spring`, `build_fasteners`. |
| `beni_export.py` | **new** — STEP per machined part, URDF + inertia JSON with a hard mass-closure check, print STL set, viewer STL set with a derived manifest. |
| `archive/manufacturing/machined_parts_spec.md` | **new** |
| `archive/manufacturing/step/*.step` | **new**, 10 files |
| `sim/beni.urdf`, `sim/beni_inertia.json` | **new** |
| `beni_prototype1_bom_and_assembly.md` | fastener schedule, masses, mass properties, tyre spec, assembly torques |
| `web/build.py` | `GROUP_ORDER` was missing the `wheel` group |
| `print_stl/`, `web/models/`, `web/index.html` | re-exported |

The URDF exporter has a **mass-closure assertion**: every gram in the assembly
must land in exactly one link. It caught the four cartridge clevis pins (15.2 g)
going nowhere on the first run, which is the kind of error that otherwise ships
into a controller as a slightly-too-light robot.

---

## 14. Recommended next actions

1. **Print `GAUGE_Fit_Coupon.stl` and measure all six bores.** Nothing else
   should be printed or machined first; PA-CF hole shrinkage decides whether the
   Ø19 bearing seats and Ø16 sleeve bore need to be modelled oversize.
2. **Send `archive/manufacturing/step/` + the spec sheet out for quote.**
3. **Close the actuator question with the supplier** (§11) before any jump
   tuning, since the jump case sits at rated torque.
4. **Load `sim/beni.urdf`** and check that the balance controller is happy with
   τ = 0.103 s and a +6.46 mm standing trim.
5. **Then run the bench sequence** already specified in design record §8 —
   dry fit, knee stack, static sweep, spring rate on a press, static load at
   17.2 / 51.5 / 275 N, drops at 20 / 50 / 100 mm, 500-cycle cable endurance.
   No powered jump until the +27° stop is confirmed never reached at 100 mm.
6. **Design the electronics for real** (§10) — that is now the largest remaining
   block of unspecified work.

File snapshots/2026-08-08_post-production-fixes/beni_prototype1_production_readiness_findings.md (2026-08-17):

# Beni Prototype 1 — Production-Readiness Audit and Findings

> **RESOLVED 2026-08-08 — see `beni_prototype1_rev2_changes.md`.**
> Every finding in Part 3 below has been closed except §3.10 (electronics, now
> modelled but still not designed), §3.11 (actuator duty cycle, now quantified —
> the 3 g jump needs ≈5.9 N·m per leg against ~4.6–5.4 N·m rated) and §3.12
> (supplier confirmations). Five automated checks were added to `beni_lib` so
> each defect class cannot recur; `beni_lib.audit_all()` reports **0 problems**.
>
> Seven *further* defects were found during the fix work, three of them hidden by
> the way the original audits were scoped — including a stale mirror that left
> the right knee with no axle, no sleeve and no spring, a `rebuild_spring()` that
> corrupted the assembly on every pose, and a `drop_comp()` that made every
> builder non-idempotent. Those are recorded in the change document, not here.
>
> This document is kept as written, as the record of what the audit found.

**Date:** 2026-08-08
**Scope:** Full context gather across the `Biped` folder and the live Fusion
model `Biped → Beni_Prototype1`, followed by an independent audit aimed at
production readiness.
**Method:** Every number below was either re-derived from first principles in
Python or measured directly out of the open Fusion document via the Fusion MCP
(B-Rep face geometry, body volumes, per-body centroids, interference analysis,
timeline inspection). Nothing here is taken on trust from the existing
documents.

---

# Part 1 — What exists

## 1.1 The machine

A **wheeled biped** in the Mondo Robotics *Beni* serial morphology:

```
body ──▶ active rotary shoulder ──▶ proximal link ──▶ passive spring knee ──▶ distal link ──▶ driven wheel
         (GIM6010-8, ±185°)          (L1 = 120 mm)     (−8° … +27°)           (L2 = 120 mm)    (GIM4305-10, Ø110)
```

Deliberately **not** an Ascento-style parallel four-bar, not an active knee, not
telescoping. The knee is purely passive: a guided compression-spring cartridge
spanning the joint. The shoulder is the only actuated leg joint; the wheel is
independently driven.

**Envelope, measured from the model:** 182.9 (X) × 217.0 (Y) × 281.3 (Z) mm,
track 168 mm, ride height (shoulder axis to ground) 209.3 mm.

## 1.2 Files in the folder

| Path | Lines | What it is |
|---|---:|---|
| `beni_prototype1_fusion_guide_rewritten.md` | 601 | The **requirements document**. Frozen kinematics, spring targets, materials rules, 12-phase workflow, acceptance checklist, §17 freeze list. This is the spec, not the design. |
| `beni_prototype1_design_record.md` | 509 | The **as-designed record**. Verification tables, motor STEP audit, lateral layout, assumptions/deviations, load cases, defects found and fixed. |
| `beni_prototype1_bom_and_assembly.md` | 255 | BOM (per-robot), fastener schedule, mass roll-up, assembly sequence, print order. |
| `beni_lib.py` | 1742 | The **parametric build source**. Geometry helpers, kinematics closed forms, part builders, posing engine, interference harness. |
| `print_stl/` | 12 STL + README | Print-ready STLs, PLA check-prints of the metal parts, two motor stand-in gauges, a 6-bore fit coupon. |
| `web/` | viewer + 24 STL | Self-contained three.js viewer with live kinematics (`index.html`, 2 MB, geometry embedded as gzip+base64). `check.py` headless-tests the posing maths in node. |
| `CAD Imports/` | 2 STEP + 2 ASCII STEP | The supplied Steadywin motor geometry — dimensional source of truth. |

## 1.3 The Fusion model, as it actually stands

Document `Beni_Prototype1` (project `Biped`, lineage `mrn7U3LF…`):

- **156 root occurrences**, **79 components**, **815 timeline entries**
- Feature mix: 217 extrudes, 212 sketches, 212 construction planes, 11 revolves,
  **1 mirror**, 162 occurrence adds
- **31 user parameters** (`L1`, `Ru`, `Rl`, `phi_stop`, `spring_rate`, …)
- 2 external references: `REF_GIM6010-8`, `REF_GIM4305-10`, plus one mirrored
  local copy of each
- **0 joints, 0 as-built joints, 0 rigid groups, 0 snapshots, 0 named views**

Motion is produced by scripted occurrence transforms (`beni_lib.set_pose`),
not by Fusion joints. That is a deliberate, documented choice.

## 1.4 The lateral stack (left leg), frozen

Everything hangs off this table. `y` is global, `+Y` = left-outboard.

| y (mm) | Feature |
|---:|---|
| 5 … 16 | shoulder motor driver cover Ø57 |
| 17 … 41 | shoulder motor housing Ø80 |
| **42** | **housing mount face — 8 × M3 @ Ø74 PCD** |
| 42 … 47 | `Chassis_Shoulder_Plate_L`, 5 mm PA-CF, Ø96 |
| **45.5** | **output mount face — 6 × M3 @ Ø25 PCD + 3 × Ø4 pins to y = 49** |
| 45.5 … 59.5 | `Shoulder_Output_Hub_L`, 7075-T6, Ø38 body → Ø56 flange |
| 47 … 51 | clock-spring harness cavity, r = 20 … 32 |
| 51.5 … 53.5 | `Shoulder_Cable_Cover_L`, 2 mm ABS |
| **59.5** | **leg inboard face** |
| 58.7 … 64.5 | proximal arm A (5 mm + 0.8 boss); 6800 bearing 58.7 … 63.7 |
| 63.7 … 85.3 | knee steel sleeve Ø16/Ø10, double-D bore |
| **64.5 … 84.5** | **spring channel, 20.0 mm** — cartridge centred on y = 74.5 |
| 84.5 … 90.3 | proximal arm B; 6800 bearing 85.3 … 90.3 |
| **89.5** | **leg outboard face** |
| 90.3 … 93.3 | `Knee_Stop_Arc_L`, 3 mm hardened steel, two-level arc slot |
| 90.3 … 96.3 | `Knee_Magnet_Carrier_L`, magnet face at 96.3 |
| 97.3 | encoder package face — **1.00 mm** air gap |
| 59.5 … 67.5 | distal wheel-end plate, 8 mm |
| **67.5** | **wheel motor mount face — 6 × M2.5 @ Ø47.5 PCD** |
| 69 … 99 | rim + tyre, Ø110 (centre y = 84) |
| **94.5** | wheel motor output flange face |
| 94.5 … 100.5 | `Wheel_Hub_L`, 7075-T6 |

Nothing rotating crosses y = 53.5, so the chassis is free below |y| ≤ 47 —
this is why the ±185° shoulder sweep is clean by construction, not just by test.

## 1.5 Motor interface geometry (audited from the supplied STEP)

**GIM6010-8 (shoulder)** — 44.0 mm long, Ø80 housing, datum = mount face at x = 0:
- Housing mount: **8 × M3 on Ø74.0 PCD**, ~4.0 mm thread
- Output mount face at **x = +3.5**: **6 × M3 on Ø25.0 PCD × 5 mm deep**
- **3 × Ø4.0 anti-rotation pins on Ø20.4 PCD**, protruding 3.5 mm
- Ø34 pilot boss is **unusable as a register** (root fillet blends to Ø36.4,
  under 0.2 mm of straight land) — the hub locates on the three dowel pins instead
- Centre is a **0.5 mm blind recess, not a through-bore** → no central cable route

**GIM4305-10 (wheel)** — 33.0 mm long, Ø53 housing:
- Housing mount: **6 × M2.5 on Ø47.5 PCD** × ~3 mm deep
- Output flange at x = −27.0: Ø37.0 OD, **3 × M3 on Ø27.0 PCD × 4 mm deep**
- Output register only **1 mm deep** → hub centres on a Ø37.3 H8 × 0.8 counterbore

---

# Part 2 — The mechanics, verified

I re-derived the entire kinematic and force chain independently. **The core
mechanism is correct.** Every checkpoint in the guide and every table in the
design record reproduces.

## 2.1 Knee kinematics

Convention: with the proximal link fixed, `distal angle = −50° − φ`.
Nominal shoulder-to-wheel vertical = **154.269 mm**, wheel exactly below the
shoulder axis at φ = 0 (X = 0.0000).

| φ | vert. compression | fore-aft | guide (v / f-a) |
|---:|---:|---:|---|
| −8° | −12.04 | +11.63 | −12.0 / 11.6 ✓ |
| 0° | 0.00 | 0.00 | 0 / 0 ✓ |
| +5° | 8.31 | −6.37 | 8.3 / 6.4 ✓ |
| +10° | 17.13 | −12.00 | 17.1 / 12.0 ✓ |
| +15° | 26.42 | −16.83 | 26.4 / 16.8 ✓ |
| +20° | 36.09 | −20.84 | 36.1 / 20.8 ✓ |
| +25° | 46.08 | −23.99 | 46.1 / 24.0 ✓ |
| +27° | 50.14 | −25.00 | — |

## 2.2 Cartridge geometry and force

Anchors: Ru = 36, Rl = 54, included angle 110° − φ.

| φ | eye-to-eye | moment arm | spring F | wheel F | guide wheel F |
|---:|---:|---:|---:|---:|---|
| −8° | 77.70 | 22.09 | 30.0 N | 8.25 N | 8.3 ✓ |
| 0° | 74.44 | 24.54 | 64.0 N | 17.09 N | 17.2 ✓ |
| +10° | 69.91 | 27.39 | 111.4 N | 29.36 N | 29.4 ✓ |
| +20° | 64.90 | 29.95 | 163.8 N | 43.50 N | 43.6 ✓ |
| +25° | 62.23 | 31.12 | 191.6 N | 51.44 N | 51.5 ✓ |
| +27° | 61.14 | 31.56 | 203.0 N | 54.80 N | — |

Stroke −8° → +25° = **15.47 mm** (guide: 15.47 ✓). Effective wheel rate
0 → +25° = **0.745 N/mm**, inside the 0.71–0.80 band. The **rising** moment arm
(22.09 → 31.56 mm) is what makes the wheel rate progressive; this is the single
most important thing not to "simplify".

## 2.3 Spring internal budget

Pin-to-pin dead length 25.57 mm. Solid height = 11.8 coils × 2.6 = 30.68 mm.

| φ | spring length | deflection | force | margin over solid |
|---:|---:|---:|---:|---:|
| −8° | 52.13 | 2.87 | 30.0 N | 21.45 |
| 0° | 48.87 | 6.13 | 64.0 N | 18.19 |
| +25° | 36.66 | 18.34 | 191.6 N | 5.98 |
| +27° | 35.57 | 19.43 | 203.0 N | **4.89** |

The spring **cannot coil-bind before the +27° metal stop**, with 4.89 mm to
spare. Rate check: `k = G·d⁴/(8·D³·n) = 79300 × 2.6⁴/(8 × 16.4³ × 9.8)
= 10.48 N/mm` vs the 10.45 target. Preload tunable 9.1 … 30.0 N by removing
0–4 × 0.5 mm shims.

## 2.4 Hard-stop load path

Knee torque at +27° = 203.0 N × 31.56 mm = **6.408 N·m**. At the stop-pin
radius of 30 mm that is **214 N**, taken as **534 N** with a 2.5× impact
factor. Path is: Ø6 hardened dowel → steel slot end → 3 × M3 in shear →
printed boss. No thin printed tab is ever the last line of defence. Correct
by design intent.

Bumpers: 7.5 mm PU block first contacts at **φ = +20.0°** and is crushed
3.67 mm (49 %) at +27°; 3.0 mm extension block contacts at **−6.5°**, crushed
0.79 mm (26 %) at −8°. Both in open-ended bays, replaceable without touching
the bearing stack.

## 2.5 Landing energy — corrected

Energy the two passive knees absorb, φ = 0 → +27° (numerically integrated, not
trapezoid-approximated): **1.776 J per knee, 3.553 J for the pair.**

A 100 mm free drop arrives at 1.40 m/s carrying:
- 3.434 J at the 3.5 kg design mass → **0 % margin**
- 3.286 J at the **3.352 kg corrected mass** (see §3.1) → **+8 % margin**

So the drop case is marginally better than the design record states, but the
conclusion is unchanged: **the shoulder must participate.** The progressive PU
bumper adds ≈ 0.7 J per knee at the very end of travel; active shoulder
yielding has to supply the rest. No oil damper is fitted, which is the correct
Prototype-1 call.

---

# Part 3 — New findings

Everything in this part is new. It was not in the design record.

## 3.1 The mass properties in the model are wrong, and there is no CoM or inertia

**Every single body in the design carries the material "Steel".** Only
appearances were assigned (`beni_lib.apply_appearances`); physical materials
were never set. Consequence:

| | value |
|---|---:|
| Fusion's own reported mass | **8174.2 g** |
| Fusion's own reported CoM | (10.78, 0.40, −69.93) mm |
| Corrected mass (densities applied by hand, per body) | **3232.2 g** modelled |
| + compute/IMU/PDB/wiring, not modelled | ~120 g |
| **Corrected robot total** | **≈ 3352 g** |
| Design mass | 3500 g |
| Margin | **≈ 148 g (4.2 %)** |

The BOM's 3304 g figure is close and essentially sound — the 48 g delta is
because `Knee_Spring_L` is modelled as its full outer *envelope* at steel
density (51.4 g modelled vs 25.3 g real spring), which over-counts by ~26 g per
leg, offset by right-leg parts missing from the model.

**Corrected CoM, computed per-body from true centroids and true densities:**

| | value |
|---|---:|
| CoM X (fore-aft, from shoulder axis) | **+11.97 mm** |
| CoM Y (lateral) | −0.17 mm |
| CoM Z | −53.60 mm |
| **CoM height above the wheel axis** | **100.7 mm** |
| Ixx (roll) | 0.0299 kg·m² |
| **Iyy (pitch — governs balance)** | **0.0208 kg·m²** |
| Izz (yaw) | 0.0144 kg·m² |
| Inverted-pendulum length | 100.7 mm → **√(L/g) = 0.101 s** |

Two things fall out of this, and both are production-critical:

1. **The CoM is 12 mm forward of the wheel contact patch at nominal stance.**
   That is a permanent standing pitch bias of 3.352 × 9.81 × 0.01197
   = **0.394 N·m**, which the wheel motors must hold continuously, or the robot
   creeps. Fix by shifting the battery and electronics aft ~12 mm — the battery
   alone (250 g of a 3.35 kg robot) needs to move about 160 mm aft to null it,
   or the chassis mass distribution needs rebalancing. Cheap to fix now,
   annoying to fix after the frame is printed.

2. **The pendulum is only 100.7 mm long.** Time constant 0.101 s. This robot is
   squat and will be twitchy — the balance controller needs a fast loop and the
   IMU placement/latency budget is tight. It is not wrong, but it is a
   consequence of putting 1000 g of shoulder motor at Z ≈ 0 and 815 g of wheel
   + wheel motor at Z ≈ −154, and it should be a conscious decision rather than
   an emergent one.

**Nothing downstream — controller, sim, URDF, Isaac/MuJoCo export — can be
built until these numbers exist in the model rather than in this document.**

## 3.2 The right leg is not a complete copy of the left

The entire right leg comes from **a single `MirrorFeature`**. Fusion's
mirror-as-new-component is not associative to features added to the source
component afterwards. Three parts and two feature sets were added after the
mirror was taken, and none propagated.

**Right-leg parts that do not exist at all** (component present, zero bodies):

| Part | Left | Right |
|---|---:|---:|
| `Knee_Axle_L` | 1 | **0** |
| `Knee_Sleeve_L` | 1 | **0** |
| `Knee_Spring_L` | 1 | **0** |

The right knee has **no axle, no sleeve, and no spring**. The right leg as
modelled cannot be built and cannot be load-analysed.

**Right-leg parts that exist but differ geometrically from the left:**

| Part | Left vol | Right vol | Δ | Missing feature |
|---|---:|---:|---:|---|
| `Proximal_Link_L(Mirror)` | 63093.07 mm³ | 70356.44 mm³ | **+7263.36** | the Ø34 root access bore (π·17²·8 = 7263.2 mm³ — exact match) |
| `Knee_Encoder_Bracket_L(Mirror)` | 2614.88 mm³ | 2726.12 mm³ | **+111.24** | the 3 × Ø5 driver-clearance holes (r = 2.5 faces: L = 3, R = 0) |

These are **exactly defects #4 and #5 from design record §11**, which were
fixed on the left and never propagated to the right. So on the right leg:

- the **six shoulder output-hub M3 screws are unreachable** — no hex key can get
  to them, and the hub is not serviceable without removing the link;
- the **three knee-stop M3 screws are covered** by the encoder bracket shelf.

`Distal_Link_L(Mirror)` was checked and is byte-identical in face signature and
volume — the divergence is limited to the two parts above.

Positionally the mirror is perfect: I verified L/R world bounding boxes for 13
part families and X/Z match to 0.000 mm with Y exactly negated in every case.
The problem is purely feature staleness, not placement.

## 3.3 The three knee-stop screw heads physically collide

`STOP_BOLT_A = (240°, 260°, 280°)` at `STOP_BOLT_R = 15.0` mm from the knee axis.

| pair | centre distance | M3 SHCS head Ø5.50 |
|---|---:|---|
| 240° ↔ 260° | 5.209 mm | **overlap 0.29 mm** |
| 260° ↔ 280° | 5.209 mm | **overlap 0.29 mm** |
| 240° ↔ 280° | 10.261 mm | clear 4.76 mm |

Fusion's interference analysis confirms it: 4 clashes (2 pairs × 2 legs) at
**1.03 mm³** each. Closed-form lens area for two Ø5.5 circles at 5.209 mm
centres × 3.0 mm head height = 1.02 mm³ — exact match.

The three screws **cannot all be fitted**. This is the fastener set that
carries the entire crash load path from the hard stop (534 N of impact shear).
The design record's driver-access audit modelled 32 hex-key envelopes and found
zero obstructions, but it never checked **head-to-head** clearance.

Minimum fix: open the angular spacing to ≥ 24° (6.25 mm centres, 0.75 mm head
gap) or move to `STOP_BOLT_R = 18` mm (6.25 mm at 20°). Either changes the arc
plate and the arm-B insert pattern. Both parts are affected on both legs.

## 3.4 The knee-stop insert bores are 0.5 mm too shallow, and the screws bottom out

| item | value |
|---|---|
| insert bore in the proximal arm-B boss | Ø4.0, y = 85.80 … 90.30 → **4.50 mm deep** |
| BOM heat-set insert | M3 brass, **5.00 mm long** → 0.50 mm too long for the bore |
| M3×8 screw seated at y = 93.30 | shank reaches y = **85.30** → 0.50 mm past the bore floor |

Confirmed by interference: `HW_SHCS_M3x8 ↔ Proximal_Link_L`, 6 clashes at
**3.53 mm³** = π × 1.5² × 0.5, exact.

Consequence: the insert stands 0.5 mm proud of the boss face, so the 3 mm steel
arc plate sits on three brass pips instead of on the printed boss; and the
screw bottoms out in the blind hole before it clamps. **The knee hard stop is
not actually fastened down.**

For contrast, the encoder-bracket inserts are correct: Ø4.0 × 5.00 mm deep,
M3×16 reaching y = 85.90, 0.60 mm clear of the floor. The bug is isolated to
the stop-arc pattern (`build_proximal_link`, the `KNEE_BOSS_B_Y1 - 4.5` cut).

The cable-cover screws show the same signature at smaller magnitude:
`HW_SHCS_M3x10 ↔ Shoulder_Cable_Cover_L`, 8 clashes at 7.07 mm³
= π × 1.5² × 1.0 → those screws run 1.0 mm past their insert bores too.

## 3.5 `beni_lib.build_all()` is not safe to run against the current model

The design record's opening line says *"Parametric build source: `beni_lib.py`
(`build_all()` reconstructs every modelled part)."* **It does not.**

**Parts in the model with no builder function anywhere in `beni_lib.py`:**

- `Chassis_Frame` (26 timeline features, 70.7 g, the part that structurally
  joins the two legs)
- `Electronics_Tray`
- `Battery_4S2200`
- `Shoulder_Cable_Spiral_L` (the harness envelope)

**And the shoulder plate has diverged from its builder.** The model's
`Chassis_Shoulder_Plate_L` carries **6 chassis-mount Ø3.4 holes** on a
rectangular grid at (X, Z) = (+30, −18), (+30, +48), (+30, +62), (−60, −18),
(−60, +48), (−60, +62), spanning y = 42 … 47. `build_shoulder_plate()` creates
**none of them** — it only cuts 8 × Ø3.4 at PCD 74, 4 × Ø3.4 at PCD 88, the Ø7
grommet and the Ø48 bore.

So calling `build_all()` today would `drop_comp('Chassis_Shoulder_Plate_L')` and
rebuild it **without the chassis interface**, silently disconnecting the two
legs from the frame, while leaving the orphaned `Chassis_Frame` in place with
its 10 now-unmatched Ø3.4 holes. The model would look fine and be unbuildable.

The build script and the model are no longer the same design. Either the
chassis builders get written and the plate builder gets its chassis holes, or
the "reproducible from source" claim has to be withdrawn — right now it is a
trap.

Related housekeeping: the timeline still contains 7 features under a component
`HW_SHCS_M3x14` that no longer exists in the assembly, and `beni_lib.PART_CLASS`
still lists `HW_SHCS_M3x14` and `HW_SHCS_M4x14` (superseded by M3x10/M4x10).
`beni_lib.ENC_PCB_Y = 97.8` with a *"1.5 mm air gap"* comment is dead code —
`build_encoder()` hard-codes 98.3 and the real gap is 1.00 mm.

## 3.6 There is not a single fillet or chamfer in the design

Timeline feature census: **217 extrudes, 11 revolves, 0 FilletFeature,
0 ChamferFeature.**

Every part is built from sharp-cornered extrusions. For the PA-CF printed
structure under impact loading, this is the highest-value structural change
available, and none of the following load-bearing re-entrant corners has a
radius:

- the root of both knee bearing bosses where they meet the fork arms
- the two ends of the 20 mm spring channel (the classic FDM crack initiation
  site — a sharp slot end in a part loaded in bending)
- the root-pad step on the proximal link (8 mm pad → 5 mm arm)
- the wheel-end plate root on the distal link (8 mm plate → 5 mm arm)
- the cartridge eye slot roots in both aluminium eyes
- every lightening-slot corner in both links

FDM parts fail at sharp internal corners, in the layer plane, long before the
nominal section stress is reached. The design record's own §5 FEA caveat
("isotropic FEA is not proof for PA-CF") is exactly right, and the mitigation
for that caveat is generous radii — which are absent.

## 3.7 The tyre has no retention and no crown

`Wheel_Tyre_L` is a **4-face plain annulus**: Ø96 ID, Ø110 OD, 30 mm wide.

- **Tyre ID Ø96.0 = rim seat OD Ø96.0.** Zero interference is modelled. As
  drawn the tyre is a free slip fit on a smooth PA-CF drum with no bead, no
  groove, no lip and no adhesive land. Under braking or a hard direction
  reversal it will rotate on the rim. A real design wants ~2 mm of stretch
  (ID Ø94) plus a retention feature.
- **No axial retention inboard.** The rim drum runs y = 69 … 104.5 and the tyre
  occupies y = 69 … 99, so there is a 5.5 mm step outboard but *nothing* at
  y = 69. The tyre can walk off inboard.
- **No crown.** A cylinder on a flat floor gives 30 mm of line contact and zero
  camber tolerance. For a balancing machine that makes lateral scrub and
  contact-point estimation worse than it needs to be; a 60–80 mm crown radius
  costs nothing.

Also: the wheel rim + tyre is **315 g of the 3352 g robot (9.4 %)** and it is
all at maximum radius, i.e. it is the dominant contributor to the wheels'
rotational inertia and therefore to how hard the balance controller has to
work. It is also the BOM's own #1 mass-reduction target.

## 3.8 Interference is genuinely clean — with one caveat worth stating

Whole-assembly analysis, coincident faces excluded, threshold 0.5 mm³:
**89 pairs, of which 88 are screw-shank-in-tap-drill modelling artifacts.**

| pair (L+R merged) | count | total mm³ | max mm³ | verdict |
|---|---:|---:|---:|---|
| motor body ↔ M3×10 | 28 | 400.72 | 16.35 | artifact (screw in motor's tapped hole) |
| M4×10 ↔ `Shoulder_Output_Hub_L` | 12 | 298.60 | 24.88 | artifact |
| M4×10 ↔ `Wheel_Hub_L` | 12 | 288.96 | 24.08 | artifact |
| motor body ↔ M2.5×12 | 12 | 122.52 | 10.21 | artifact |
| motor body ↔ M3×8 | 6 | 76.87 | 12.81 | artifact |
| M3×10 ↔ `Shoulder_Cable_Cover_L` | 8 | 56.55 | 7.07 | **real — §3.4, screw 1.0 mm past bore** |
| `Knee_Axle_L` ↔ `Knee_Magnet_Carrier_L` | 1 | 32.11 | 32.11 | artifact (M4 stud in tap drill), documented |
| M3×8 ↔ `Proximal_Link_L` | 6 | 21.21 | 3.53 | **real — §3.4, screw 0.5 mm past bore** |
| M3×8 ↔ M3×8 | 4 | 4.12 | 1.03 | **real — §3.3, screw heads collide** |

So the design record's "interference clear" claim holds for the *structure*, and
the two artifacts it documented are real artifacts. But the audit was run with
screws filtered out, and filtering the screws is exactly what hid §3.3 and
§3.4. **Three real defects were sitting in the screw-vs-part results.**

## 3.9 Manufacturing outputs do not exist for the machined parts

`print_stl/` is genuinely good work — the Ø19/Ø16/Ø10/Ø6/Ø4.05/Ø4 six-bore fit
coupon and the two motor stand-in gauges are exactly the right way to de-risk
before the motors land, and the "print this first" ordering is correct.

But there are **10 machined part families** — `Shoulder_Output_Hub_L`,
`Wheel_Hub_L`, `Cart_Upper_Eye_L`, `Cart_Lower_Eye_L`, `Knee_Axle_L`,
`Knee_Sleeve_L`, `Knee_Magnet_Carrier_L`, `Knee_Stop_Arc_L`, `Cart_Guide_Rod_L`,
`Cart_Preload_Shim_L` — and for those there is:

- **no STEP or Parasolid export** (only STL, from which no shop will quote or
  program)
- **no dimensioned drawing** (0 drawing documents in the project)
- **no tolerance callouts anywhere in CAD** — the H7/H8/h6 fits exist only as
  prose in the BOM (`Ø4.05 H7`, `Ø37.3 H8`, `Ø10 h6`, `8.40 across flats`)
- **no surface-finish, heat-treat or hardness callouts** — `Knee_Stop_Arc_L` is
  described as "hardened" with no spec, and it is the crash load path
- **no material certs called out** for the 7075-T6 or the spring steel

This is the single largest gap between "verified CAD" and "production". A
machine shop cannot start.

## 3.10 The electronics and harness are placeholders

Modelled: `Battery_4S2200` (a 77.6 cm³ rectangular block), `Electronics_Tray`
(an 8.5 cm³ flat panel), `Shoulder_Cable_Spiral_L` (a swept harness envelope).

Not modelled anywhere: compute board, IMU (and there is no defined IMU mounting
location or orientation datum — which the balance controller needs to know to
0.1°), CAN bus wiring and termination, power distribution, e-stop/kill switch,
charge port, connectors, fusing, or any chassis skin/cover. The 120 g line item
in the BOM is a placeholder for all of it.

Two specific consequences:

- **No IMU datum** means the corrected CoM and inertia of §3.1 have nowhere to
  be referenced from.
- The **encoder air gap needs re-checking against the real part.** The model
  puts the magnet face at y = 96.3 and the *package* face at 97.3 → 1.00 mm.
  But the AS5048A sensing die sits inside its package, so the true
  magnet-to-die gap will be ≈ 1.5–1.7 mm. With a Ø6 × 2.5 diametric magnet that
  is at the upper end of usable and will cost signal amplitude. The design
  record's "encoder die ↔ magnet 1.00 mm — the design air gap" line is
  measuring to the package, not the die.

## 3.11 Actuator sizing has never been checked against the duty cycle

The structure is proof-designed to 25 N·m at the shoulder, which is
conservative and correct. But **nobody has checked whether the motor can
produce the motion the design depends on.** First-order numbers:

| case | required | GIM6010-8 capability |
|---|---:|---|
| hold the leg statically (0.55 kg at ~90 mm) | 0.49 N·m | trivial |
| **drive a 3 g jump through the leg (lever ~120 mm)** | **≈ 5.9 N·m per leg** | ~4.6–5.4 N·m **rated**, 11–17.9 N·m stall |

The jump — the whole point of the passive knee — sits **right at or just above
continuous rated torque** and depends on peak/stall capability. That is
probably fine for a short impulse, but it is the design's central assumption and
it is currently unverified. It also makes the exact variant and bus voltage
(§3.12) a gating item, not a footnote.

Wheel side is comfortable:

| case | required per wheel | GIM4305-10 |
|---|---:|---|
| accelerate at 1 m/s² | 0.092 N·m | ample |
| hold the 12 mm CoM offset of §3.1 | 0.197 N·m | ample |
| 15° slope | 0.234 N·m | ample |

## 3.12 Items still genuinely blocked on outside information

Carried forward from design record §9, all still open:

1. **Exact GIM6010-8 variant, bus voltage, driver firmware, CAN and
   absolute-encoder configuration.** Now a gating item because of §3.11.
2. **Spring supplier confirmation** — Ø19 OD × 2.6 wire × 55 free × ~9.8 active
   coils, closed and ground, chrome-silicon ASTM A877/A877M, shot-peened and
   preset. Need achievable rate tolerance (±5 % assumed) and actual solid height
   (30.68 mm assumed, and the +27° margin is only 4.89 mm).
3. **PU bumper compound.** 49 % crush on the flexion bumper is at the upper end
   of sensible for ~90 A polyurethane. Bench-test tuning item.
4. **PA-CF print parameters.** All mass and section figures assume the modelled
   solid is realised. A lightly-infilled 5 mm knee arm is not the part that was
   analysed.

---

# Part 4 — What is solid, and should not be touched

It is worth being explicit about this, because the list of findings above is
long and the underlying design is good.

- **The kinematic core is correct and fully verified.** Ru/Rl/110° anchor
  geometry, the rising moment arm, the progressive wheel rate, the 154.269 mm
  nominal, the wheel directly under the shoulder — all reproduce exactly.
- **The spring cannot coil-bind before the metal stop.** 4.89 mm of margin,
  independently confirmed.
- **The 30 mm leg width is a forced consequence, not a choice**, and the
  reasoning in design record §4.1 is right: the guide's frozen anchor geometry
  fixes the minimum moment arm at 22.09 mm, which mandates a 20 mm clear
  channel, which leaves 5 mm arms — and a 6800 bearing (Ø19) needs that.
- **Locating the shoulder hub on the three Ø4 anti-rotation pins instead of the
  Ø34 pilot boss is the right call**, and the STEP evidence for it (root fillet
  blends to Ø36.4) is sound.
- **The clock-spring harness solution is correct** given the motor has no
  through-bore: r = 20 … 32 × 4 mm cavity, ~400 mm of Ø3.0 cable giving ≈ 470°
  against 370° needed, 27 % margin, strain relief on both ends.
- **The ±185° sweep is clean by construction as well as by test** — the
  Y-separation argument (all chassis within |y| ≤ 51, leg's inboard-most part
  is a body of revolution) makes the clearance rotation-invariant.
- **Assembly and disassembly logic is genuinely well thought through.** Spring
  changes with one clevis pin. Wheel motor removable with the leg assembled.
  Axle insertable only from inboard, and the sequence respects it.
- **`print_stl/` is exemplary de-risking.** The fit coupon and motor gauges let
  the whole knee and shoulder stack be dry-assembled before any motor or any
  metal arrives.
- **The web viewer is a real asset**, and `web/check.py` — headless-testing the
  posing maths in node with a stubbed three.js — is the right instinct. It
  passes: 81/81 poses, `update()` ok, all 7 groups present.

---

# Part 5 — Recommended path to production readiness

Ordered by (blocking × cheapness). Items 1–4 are all defects that make the
current model unbuildable or unfaithful; they should be closed before any new
design work.

### Tier 0 — the model is currently wrong (do these first)

1. **Rebuild the right leg from the left, properly.** Delete the single
   `MirrorFeature` output and re-mirror after all left-leg features are final,
   or better: drive both legs from `beni_lib` with a `side` parameter so they
   cannot diverge again. Recovers the missing axle, sleeve and spring, and the
   two stale parts. *(§3.2)*
2. **Fix the knee-stop screw pattern.** Open to ≥ 24° spacing or move to
   r = 18 mm. Touches `Knee_Stop_Arc_L` and the arm-B insert pattern on both
   legs. *(§3.3)*
3. **Deepen the stop-arc insert bores to 5.0 mm** (and re-check every blind
   insert bore against its insert length and screw length — the cable cover has
   the same bug at 1.0 mm). *(§3.4)*
4. **Assign real physical materials to all 79 components** so Fusion reports
   true mass, CoM and inertia. Then re-run the roll-up and publish the CoM and
   inertia tensor as model output rather than as a table in a markdown file.
   *(§3.1)*

### Tier 1 — required before anything is manufactured

5. **Reconcile `beni_lib.py` with the model.** Write `build_chassis_frame()`,
   `build_electronics_tray()`, `build_battery()`, `build_cable_spiral()`; add
   the 6 chassis-mount holes to `build_shoulder_plate()`; delete the dead
   `HW_SHCS_M3x14`/`M4x14` entries and the stale `ENC_PCB_Y`. Then prove it:
   `build_all()` into a scratch document and diff volumes against the master.
   Until that diff is clean, put a warning at the top of the design record.
   *(§3.5)*
6. **Add fillets.** Start with the spring-channel ends, both bearing-boss roots,
   and the two root-pad steps. R2–R3 where package allows, R1 minimum.
   Highest structural return of anything on this list. *(§3.6)*
7. **Produce real manufacturing outputs for the 10 machined parts:** STEP 214
   exports, dimensioned drawings with the H7/H8/h6 fits and across-flats
   tolerances actually called out, hardness spec on `Knee_Stop_Arc_L`, material
   spec on the 7075 and the spring. *(§3.9)*

### Tier 2 — design maturity

8. **Fix the tyre/rim interface:** tyre ID to Ø94 for 2 mm stretch, add a
   retention bead or groove, add an inboard lip, add a 60–80 mm crown. *(§3.7)*
9. **Rebalance for CoM.** Move the battery and electronics aft to null the
   12 mm forward offset, and decide deliberately whether 100.7 mm of pendulum
   height is what you want. *(§3.1)*
10. **Define the electronics and harness for real** — compute, IMU with a stated
    mounting datum and orientation, CAN routing, power distribution, e-stop,
    charge port, chassis skin. *(§3.10)*
11. **Verify the encoder air gap against the real AS5048A package**, not the
    package face. Consider a thicker magnet or a shorter carrier. *(§3.10)*
12. **Close the actuator question:** confirm the GIM6010-8 variant and bus
    voltage, then check the jump duty cycle against the real torque-speed curve
    rather than against the rated figure. *(§3.11, §3.12)*

### Tier 3 — the things that make it a robot rather than an assembly

13. **Add real Fusion joints with limits** (shoulder revolute ±185°, knee
    revolute −8…+27, wheel revolute) so the model is movable by someone who
    does not have `beni_lib.py`, and so joint limits are enforced by the CAD
    rather than by convention.
14. **Export a URDF/MJCF** with the corrected masses and inertias from item 4.
    This is the actual handoff to controls and sim, and it is impossible today.
15. **Extend the audit harness to catch what it missed.** `beni_lib` needs a
    fastener audit that checks head-to-head clearance, screw length vs blind
    hole depth, and insert length vs bore depth — the three checks whose absence
    produced §3.3 and §3.4 — and an L/R parity check that compares per-part
    volumes and face signatures, which would have caught §3.2 immediately.
16. **Then run the bench sequence** already correctly specified in design record
    §8: dry fit → knee stack → static sweep → spring rate on a press → static
    load 17.2/51.5/275 N → drops at 20/50/100 mm → 500-cycle cable endurance.
    No powered jump until the +27° stop is confirmed never reached at 100 mm.

---

## Summary

The **mechanism is right and the engineering reasoning behind it is sound** —
every kinematic, force, stroke, coil-bind and energy number in the existing
documents reproduces independently, and several of the non-obvious calls (dowel
location instead of the pilot boss, 30 mm leg width, clock-spring harness,
metal-backed stop path) are correct and well-argued.

What is missing is the transition from *verified geometry* to *manufacturable
product*. Concretely: the right leg is an incomplete copy, three fastener
defects would stop the build on the bench, the model has no true mass
properties and therefore no CoM or inertia for controls, the build script no
longer reproduces the model, there is not one fillet in a design that lives or
dies on FDM impact strength, and the ten machined parts have no drawings.

None of that is deep — it is all a few days of focused work, and items 1–4 are
the ones that matter most because until they are closed, every downstream
number is being computed against a model that does not describe the robot.

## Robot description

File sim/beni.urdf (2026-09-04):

<?xml version="1.0"?>
<!-- Beni Prototype 1.  Generated from the Fusion model by
     beni_export.export_urdf(); masses and inertias are the
     model's own, not estimates.
     Frame: X forward, Y left, Z up.  All joints rotate about +Y.
     The knee is PASSIVE: the limits below are the mechanical
     stops, and the spring must be supplied by the simulator as
     a joint spring of ~10.45 N/mm acting through the cartridge
     moment arm (22.09 mm at -8 deg rising to 31.56 mm at +27).
-->
<robot name="beni_prototype1">

  <link name="base_link">
    <inertial>
      <origin xyz="-0.011033 -0.000000 0.013283" rpy="0 0 0"/>
      <mass value="1.628720"/>
      <inertia ixx="0.002838802" iyy="0.002627748" izz="0.002774378" ixy="0.000000000" iyz="-0.000000000" ixz="0.000385413"/>
    </inertial>
  </link>

  <link name="l_thigh">
    <inertial>
      <origin xyz="0.037853 0.017628 -0.031797" rpy="0 0 0"/>
      <mass value="0.222429"/>
      <inertia ixx="0.000406136" iyy="0.000745561" izz="0.000444612" ixy="-0.000086953" iyz="0.000081366" ixz="0.000318398"/>
    </inertial>
  </link>
  <joint name="l_shoulder" type="revolute">
    <parent link="base_link"/>
    <child link="l_thigh"/>
    <origin xyz="0.000000 0.052500 0.000000" rpy="0 0 0"/>
    <axis xyz="0 1 0"/>
    <limit lower="-3.228859" upper="3.228859" effort="25.0" velocity="30.0"/>
  </joint>

  <link name="l_shank">
    <inertial>
      <origin xyz="-0.064474 0.003129 -0.056064" rpy="0 0 0"/>
      <mass value="0.410591"/>
      <inertia ixx="0.000483486" iyy="0.001103798" izz="0.000685575" ixy="0.000027453" iyz="0.000019943" ixz="-0.000465239"/>
    </inertial>
  </link>
  <joint name="l_knee" type="revolute">
    <parent link="l_thigh"/>
    <child link="l_shank"/>
    <origin xyz="0.091925 0.022000 -0.077135" rpy="0 0 0"/>
    <axis xyz="0 1 0"/>
    <limit lower="-0.139626" upper="0.471239" effort="25.0" velocity="30.0"/>
  </joint>

  <link name="l_wheel">
    <inertial>
      <origin xyz="0.000000 0.004911 0.000000" rpy="0 0 0"/>
      <mass value="0.207060"/>
      <inertia ixx="0.000213508" iyy="0.000373144" izz="0.000213508" ixy="-0.000000000" iyz="0.000000000" ixz="0.000000000"/>
    </inertial>
  </link>
  <joint name="l_wheel" type="continuous">
    <parent link="l_shank"/>
    <child link="l_wheel"/>
    <origin xyz="-0.091925 0.009500 -0.077135" rpy="0 0 0"/>
    <axis xyz="0 1 0"/>
  </joint>

  <link name="r_thigh">
    <inertial>
      <origin xyz="0.037853 -0.017628 -0.031797" rpy="0 0 0"/>
      <mass value="0.222429"/>
      <inertia ixx="0.000406136" iyy="0.000745561" izz="0.000444612" ixy="0.000086953" iyz="-0.000081366" ixz="0.000318398"/>
    </inertial>
  </link>
  <joint name="r_shoulder" type="revolute">
    <parent link="base_link"/>
    <child link="r_thigh"/>
    <origin xyz="0.000000 -0.052500 0.000000" rpy="0 0 0"/>
    <axis xyz="0 1 0"/>
    <limit lower="-3.228859" upper="3.228859" effort="25.0" velocity="30.0"/>
  </joint>

  <link name="r_shank">
    <inertial>
      <origin xyz="-0.064474 -0.003142 -0.056064" rpy="0 0 0"/>
      <mass value="0.410591"/>
      <inertia ixx="0.000483453" iyy="0.001103798" izz="0.000685541" ixy="-0.000027283" iyz="-0.000019795" ixz="-0.000465239"/>
    </inertial>
  </link>
  <joint name="r_knee" type="revolute">
    <parent link="r_thigh"/>
    <child link="r_shank"/>
    <origin xyz="0.091925 -0.022000 -0.077135" rpy="0 0 0"/>
    <axis xyz="0 1 0"/>
    <limit lower="-0.139626" upper="0.471239" effort="25.0" velocity="30.0"/>
  </joint>

  <link name="r_wheel">
    <inertial>
      <origin xyz="0.000000 -0.004911 0.000000" rpy="0 0 0"/>
      <mass value="0.207060"/>
      <inertia ixx="0.000213508" iyy="0.000373144" izz="0.000213508" ixy="0.000000000" iyz="0.000000000" ixz="0.000000000"/>
    </inertial>
  </link>
  <joint name="r_wheel" type="continuous">
    <parent link="r_shank"/>
    <child link="r_wheel"/>
    <origin xyz="-0.091925 -0.009500 -0.077135" rpy="0 0 0"/>
    <axis xyz="0 1 0"/>
  </joint>

</robot>

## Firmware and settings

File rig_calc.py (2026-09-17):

#!/usr/bin/env python3
"""Load, travel, mass and dynamics arithmetic for the Beni single-leg test rig.

Everything here is recomputed from the frozen inputs rather than copied from
`fusion_brief_single_leg_rig.md`, so that the brief's numbers get checked instead
of inherited.  Frozen sources:

  * kinematics + spring geometry  beni_prototype1_fusion_guide_rewritten.md §4-§9
  * motor interfaces              beni_prototype1_design_record.md §2
  * per-link masses/inertias      sim/beni_inertia.json

Run:  python3 rig_calc.py
"""

import functools
import json
import math
import os

import numpy as np

ROOT = os.path.dirname(os.path.abspath(__file__))
G = 9.80665

# ----------------------------------------------------------- frozen kinematics
A_NOM = 50.0          # nominal link angle from downward vertical, deg
L1 = L2 = 120.0       # link lengths, mm
RU, RL = 36.0, 54.0   # cartridge pivot radii from the knee axis, mm
CART_ANG = 110.0      # included anchor angle at nominal, deg
PHI_EXT, PHI_STOP = -8.0, 27.0
PHI_DESIGN = 25.0
WHEEL_R = 55.0        # Ø110 OD

SPRING_RATE = 10.45   # N/mm
SPRING_FREE = 55.0    # mm
DEAD_LENGTH = 25.57   # pin-to-pin dead length incl. 2.0 mm of shims, mm

# ------------------------------------------------------------- rig hard inputs
MGN12H = dict(L=45.4, W=27.0, H=13.0, mass_g=54.0,
              C=3720.0, C0=5880.0, MR=38.22, MP=36.26, MY=36.26,
              screw='M3', thread_deep=3.5, pattern=20.0)
RAIL_H = 8.0          # MGN12 rail section height, mm
BLOCK_CENTRES = 80.0  # carriage block spacing, mm
HALF_TRACK = 84.0     # wheel centre plane, mm from the sagittal plane
SHOULDER_STALL = 11.0     # N·m, 24 V GIM6010-8
SHOULDER_PROOF = 25.0     # N·m structural screening load
JUMP_TORQUE = 5.9         # N·m the jump needs
TORQUE_ARM = 200.0        # mm

# Rig lateral stack, AS BUILT.  The carriage bolts to Chassis_Shoulder_Plate_L's
# five existing frame-bolt holes on the motor's FRONT face, not to the motor's
# rear flange: the rear flange is stiffer but the GAUGE shoulder coupon models
# only the front 9.5 mm of the motor, and the brief gates every interface on the
# coupons.  See the design record §1.1.
MOTOR_FRONT_FACE_Y = 42.0   # 8 × M3 Ø74 PCD, thread 4.0 deep from here
PANEL_OUTER_Y = 47.0        # Chassis_Shoulder_Plate_L, 5 mm
CARRIAGE_T = 8.0            # PA-CF carriage plate thickness, mm
BLOCK_H = 13.0              # MGN12H
RAIL_PLANE_Y = MOTOR_FRONT_FACE_Y - CARRIAGE_T - BLOCK_H   # 21.0

# Chassis_Shoulder_Plate_L's five existing frame-bolt holes, (X, Z), measured off
# the model (design record §2.2).  In Mode A these are the ONLY structural joint
# between the leg and the stand -- mirrored here from rig_lib.PANEL_FRAME_BOLTS
# so this script stays runnable outside Fusion.
PANEL_FRAME_BOLTS = [(-60.0, -18.0), (-60.0, 48.0), (-60.0, 62.0),
                     (30.0, 48.0), (30.0, 62.0)]


# ------------------------------------------------------------- knee/spring model
def cart_len(phi):
    """Cartridge pivot eye-to-eye length, mm."""
    a = math.radians(CART_ANG - phi)
    return math.sqrt(RU ** 2 + RL ** 2 - 2 * RU * RL * math.cos(a))


def cart_arm(phi):
    """Spring line-of-action moment arm about the knee axis, mm."""
    a = math.radians(CART_ANG - phi)
    return RU * RL * math.sin(a) / cart_len(phi)


def spring_force(phi):
    """Compression-spring force, N."""
    return SPRING_RATE * (SPRING_FREE - (cart_len(phi) - DEAD_LENGTH))


def knee_torque(phi):
    """Spring torque about the knee axis, N·mm."""
    return spring_force(phi) * cart_arm(phi)


def wheel_xz(phi):
    """Wheel axis position relative to the shoulder axis, mm, shoulder fixed."""
    kx = L1 * math.sin(math.radians(A_NOM))
    kz = -L1 * math.cos(math.radians(A_NOM))
    d = math.radians(-A_NOM - phi)
    return kx + L2 * math.sin(d), kz - L2 * math.cos(d)


def dz_dphi(phi):
    """d(shoulder-to-wheel vertical)/dφ, mm per radian.  Positive = wheel rises."""
    return L2 * math.sin(math.radians(A_NOM + phi))


def ground_force(phi):
    """Vertical force at the wheel held by the spring, N."""
    return knee_torque(phi) / dz_dphi(phi)


def compression(phi):
    """Vertical wheel compression from φ=0, mm (positive = compressed)."""
    return wheel_xz(phi)[1] - wheel_xz(0.0)[1]


def phi_at_compression(x):
    """Invert compression(φ)."""
    lo, hi = -8.0, 40.0
    for _ in range(200):
        mid = (lo + hi) / 2.0
        if compression(mid) < x:
            lo = mid
        else:
            hi = mid
    return (lo + hi) / 2.0


def phi_at_force(f):
    lo, hi = -7.999, 27.0
    for _ in range(200):
        mid = (lo + hi) / 2.0
        if ground_force(mid) < f:
            lo = mid
        else:
            hi = mid
    return (lo + hi) / 2.0


def wheel_rate(phi, h=1e-4):
    """Tangent vertical rate at the wheel, N/mm."""
    x0, x1 = compression(phi - h), compression(phi + h)
    return (ground_force(phi + h) - ground_force(phi - h)) / (x1 - x0)


@functools.lru_cache(maxsize=1)
def spring_energy_curve():
    """Return the cumulative spring-work curve over the allowed travel."""
    xs = np.linspace(0.0, compression(PHI_STOP), 4000)
    fs = np.array([ground_force(phi_at_compression(v)) for v in xs])
    segment_work = (fs[:-1] + fs[1:]) * 0.5 * np.diff(xs)
    energy = np.concatenate(([0.0], np.cumsum(segment_work))) / 1000.0
    return xs, energy


def spring_energy(x):
    """Work done compressing the leg from φ=0 to compression x mm, in J."""
    xs, energy = spring_energy_curve()
    if not xs[0] <= x <= xs[-1]:
        raise ValueError(f'compression {x:.3f} mm is outside the energy curve')
    return float(np.interp(x, xs, energy))


# ------------------------------------------------------------------- verification
def check_frozen():
    print('=' * 78)
    print('1.  FROZEN-INPUT VERIFICATION  (guide §4/§5/§6 must be reproduced)')
    print('=' * 78)
    print('  φ      vert     guide |  fore-aft  guide |  eye-eye  guide |'
          '  arm    guide |  F_wheel guide')
    ref = {-8: (-12.0, 11.6, 77.70, 22.09, 8.3), 0: (0.0, 0.0, 74.44, 24.54, 17.2),
           5: (8.3, 6.4, None, None, 23.1), 10: (17.1, 12.0, 69.91, 27.39, 29.4),
           15: (26.4, 16.8, None, None, 36.2), 20: (36.1, 20.8, 64.90, 29.95, 43.6),
           25: (46.1, 24.0, 62.23, 31.12, 51.5)}
    w0 = wheel_xz(0.0)
    worst = 0.0
    for phi in sorted(ref):
        x, z = wheel_xz(float(phi))
        vert, fore = z - w0[1], -(x - w0[0])
        ee, arm, fw = cart_len(phi), cart_arm(phi), ground_force(float(phi))
        r = ref[phi]
        errs = [abs(vert - r[0]), abs(fore - r[1]), abs(fw - r[4])]
        if r[2]:
            errs += [abs(ee - r[2]), abs(arm - r[3])]
        worst = max(worst, max(errs))
        print(f'  {phi:+3d}  {vert:8.2f} {r[0]:8.1f} | {fore:8.2f} {r[1]:6.1f} | '
              f'{ee:8.2f} {str(r[2] or "-"):>7} | {arm:6.2f} {str(r[3] or "-"):>6} | '
              f'{fw:7.2f} {r[4]:5.1f}')
    print(f'\n  worst deviation from the frozen tables: {worst:.3f}'
          '  → model agrees, so every number below is built on it')
    print(f'  shoulder-to-wheel vertical at nominal: {-wheel_xz(0.0)[1]:.3f} mm'
          '   (guide ~154.3)')
    k_sec = ground_force(25.0) - ground_force(0.0)
    k_sec /= compression(25.0)
    print(f'  secant wheel rate 0→+25°:  {k_sec * 1000:.1f} N/m'
          f'   ({k_sec:.4f} N/mm)   brief §4.3 says 744 N/m')
    print(f'  tangent wheel rate at φ=0: {wheel_rate(0.0) * 1000:.1f} N/m'
          f'   at φ=+25°: {wheel_rate(25.0) * 1000:.1f} N/m'
          '   (guide band 710-800)')
    return k_sec


# ----------------------------------------------------------------- mass budget
def mass_budget():
    print()
    print('=' * 78)
    print('2.  MASS BUDGET AND THE SPRUNG/UNSPRUNG SPLIT')
    print('=' * 78)
    with open(os.path.join(ROOT, 'sim', 'beni_inertia.json')) as fh:
        j = json.load(fh)
    L = j['legs']['L']
    thigh = L['thigh']['mass_kg']
    shank = L['shank']['mass_kg']
    wheel = L['wheel']['mass_kg']
    base = j['base']['mass_kg']
    total = base + 2 * (thigh + shank + wheel)
    leg = thigh + shank + wheel
    half = total / 2.0
    print(f'  robot total (inertia json)      {total:8.4f} kg'
          '   authoritative source: design record §14')
    print(f'  one leg  thigh+shank+wheel      {leg:8.4f} kg'
          f'   ({thigh:.4f} + {shank:.4f} + {wheel:.4f})')
    print(f'  half the robot = slide target   {half:8.4f} kg')
    print(f'  → carriage + plate + motor + ballast budget   {half - leg:8.4f} kg'
          '   (brief: 0.8069)')

    print('\n  What actually goes on the slide (this design):')
    fixed = [('Chassis_Shoulder_Plate_L, 5 mm PA-CF Ø96', 0.0400),
             ('2 × MGN12H blocks @ 54 g', 2 * MGN12H['mass_g'] / 1000.0),
             ('RIG_Carriage, 8 mm PA-CF skeleton plate', 0.1250),
             ('RIG_Ballast_Tray + mode-pin ear + drop ledge', 0.0450),
             ('fasteners, M3 × 8 sets + mode pin', 0.0300)]
    sub = sum(v for _, v in fixed)
    for nm, v in fixed:
        print(f'    {nm:<48s} {v * 1000:7.1f} g')
    print(f'    {"subtotal, everything but the motor":<48s} {sub * 1000:7.1f} g')
    print('\n  C4 is unresolved, so both motor masses are carried through:')
    for motor in (0.388, 0.500):
        on_slide = sub + motor + leg
        ballast = half - on_slide
        print(f'    GIM6010-8 at {motor * 1000:.0f} g → on the slide '
              f'{on_slide:.4f} kg, ballast to reach {half:.4f} = '
              f'{ballast * 1000:+7.1f} g'
              f'{"   ← OVERSHOOT, must remove mass" if ballast < 0 else ""}')

    print('\n  Sprung / unsprung split (the knee spring sits thigh↔shank):')
    unsprung = shank + wheel
    for motor in (0.388, 0.500):
        sprung = sub + motor + thigh
        tot = sprung + unsprung
        print(f'    motor {motor * 1000:.0f} g:  sprung {sprung:.4f} kg   '
              f'unsprung {unsprung:.4f} kg   total {tot:.4f} kg   '
              f'unsprung = {100 * unsprung / tot:.1f} %')
    return dict(thigh=thigh, shank=shank, wheel=wheel, leg=leg, half=half,
                sub=sub, unsprung=unsprung, json=j)


# ------------------------------------------------------------- drop / energy
def drop_table(half):
    print()
    print('=' * 78)
    print('3.  DROP SERIES, SPRING-LIMITED FORCE AND THE PASSIVE CEILING')
    print('=' * 78)
    w = half * G
    print(f'  weight on the slide {w:.2f} N  ({half:.4f} kg)')
    phi_eq = phi_at_force(w)
    print(f'  free-standing equilibrium: F = {w:.2f} N → φ_eq = {phi_eq:+.2f}°,'
          f' wheel compression {compression(phi_eq):+.2f} mm')
    print(f'  ride height, shoulder axis to floor at φ_eq: '
          f'{-wheel_xz(phi_eq)[1] + WHEEL_R:.2f} mm'
          f'   (at φ=0: {-wheel_xz(0.0)[1] + WHEEL_R:.2f} mm)')

    print('\n  Energy balance  ∫F dx = m·g·(h + x),  x measured from φ = 0:')
    print('   drop    compression    φ_peak   peak force   note')
    rows = []
    for h in (20, 30, 40, 49, 50, 60, 70, 80, 90, 100):
        lo, hi = 0.0, compression(PHI_STOP)
        for _ in range(80):
            mid = (lo + hi) / 2.0
            if spring_energy(mid) < w * (h + mid) / 1000.0:
                lo = mid
            else:
                hi = mid
        x = (lo + hi) / 2.0
        phi = phi_at_compression(x)
        f = ground_force(phi)
        note = ''
        if phi >= PHI_STOP - 1e-6:
            note = 'BOTTOMS OUT on the +27° metal stop'
        elif phi >= 24.0:
            note = 'past the +24° gate'
        elif phi >= PHI_DESIGN:
            note = 'past the +25° design point'
        rows.append((h, x, phi, f, note))
        print(f'  {h:4d} mm   {x:7.2f} mm   {phi:+7.2f}°   {f:7.2f} N   {note}')

    # passive ceiling: drop height that just reaches the +25° design point
    def h_for_phi(target):
        x = compression(target)
        e = spring_energy(x)
        return e * 1000.0 / w - x
    for tgt, label in ((PHI_DESIGN, '+25° design point'),
                       (24.0, '+24° step-10 gate'),
                       (PHI_STOP, '+27° metal hard stop')):
        print(f'  drop that just reaches {label:<20s} '
              f'{h_for_phi(tgt):7.2f} mm   (peak {ground_force(tgt):.2f} N)')
    fmax = ground_force(PHI_STOP)
    print(f'\n  Spring-limited peak force: {ground_force(PHI_DESIGN):.2f} N at '
          f'+25°, {fmax:.2f} N against the +27° stop.')
    print('  The spring is the softest element in the load path, so nothing '
          'downstream\n  can see more than this however hard the leg is dropped.')
    return rows, fmax, phi_eq


# ------------------------------------------------------------------- moments
def moment_check(fmax):
    print()
    print('=' * 78)
    print('4.  MGN12H MOMENT CHECK FOR THE AS-DESIGNED OVERHANG')
    print('=' * 78)
    rail_face_y = RAIL_PLANE_Y
    print('  As built: carriage -> the panel\'s five frame-bolt holes on the')
    print('  motor\'s FRONT face, which reproduces brief §4.1 exactly.')
    print(f'    rail mounting plane (column outboard face)   y = {rail_face_y:+7.2f}')
    print(f'    + MGN12H block height {MGN12H["H"]:.1f}                   '
          f'y = {rail_face_y + MGN12H["H"]:+7.2f}')
    print(f'    + RIG_Carriage {CARRIAGE_T:.1f} mm                        '
          f'y = {MOTOR_FRONT_FACE_Y:+7.2f}  = motor front face')
    print(f'    + Chassis_Shoulder_Plate_L 5.0               '
          f'y = {PANEL_OUTER_Y:+7.2f}')
    print(f'    wheel centre plane (half-track)              '
          f'y = {HALF_TRACK:+7.2f}')
    over = HALF_TRACK - rail_face_y
    print(f'  → lateral overhang, rail plane to wheel plane  {over:7.2f} mm'
          f'   (brief §4.1: 63.0 -> %s)'
          % ('MATCHES' if abs(over - 63.0) < 0.01 else 'DIFFERS'))

    print('\n  Loads, and what they do to a block:')
    m_imp = fmax * over / 1000.0
    m_stall = SHOULDER_STALL
    # a fore-aft ground reaction from stall torque also rolls the block
    lever_z = -wheel_xz(0.0)[1]
    f_x = SHOULDER_STALL * 1000.0 / lever_z
    m_roll = f_x * over / 1000.0
    print(f'    spring-limited impact {fmax:.1f} N × {over:.1f} mm'
          f'          → {m_imp:6.2f} N·m  about X  (pitch, MP {MGN12H["MP"]:.2f})')
    print(f'    shoulder stall {m_stall:.1f} N·m about the motor axis'
          f'      → {m_stall:6.2f} N·m  about Y  (yaw,   MY {MGN12H["MY"]:.2f})')
    print(f'    its ground reaction {f_x:.1f} N × {over:.1f} mm'
          f'      → {m_roll:6.2f} N·m  about Z  (roll,  MR {MGN12H["MR"]:.2f})')
    vec = math.sqrt(m_imp ** 2 + m_stall ** 2)
    print(f'    vector sum of the two perpendicular-to-rail components'
          f'  {vec:6.2f} N·m')
    print('\n   case                     moment   fs 1 block   fs 2 blocks')
    for nm, m, cap in (('impact only', m_imp, MGN12H['MP']),
                       ('stall only', m_stall, MGN12H['MY']),
                       ('roll from stall', m_roll, MGN12H['MR']),
                       ('vector sum imp+stall', vec, MGN12H['MP'])):
        print(f'   {nm:<24s} {m:6.2f}     {cap / m:8.2f}     {2 * cap / m:8.2f}')
    print(f'\n   clone-rail derate 30 %, 2 blocks: fs = '
          f'{0.7 * 2 * MGN12H["MP"] / vec:.2f}'
          f'   ... 1 block: fs = {0.7 * MGN12H["MP"] / vec:.2f}  (below spec)')
    print(f'   vertical load check: {(0.5 + 1.645) * G:.1f} N against C0 '
          f'{MGN12H["C0"]:.0f} N → fs {MGN12H["C0"] / ((0.5 + 1.645) * G):.0f}'
          '  (irrelevant, as the brief says)')
    return over


# -------------------------------------------------------------- travel budget
def travel_budget(rows, phi_eq):
    print()
    print('=' * 78)
    print('5.  RAIL TRAVEL BUDGET  — where the brief\'s 300 mm rail fails')
    print('=' * 78)
    span = MGN12H['L'] + BLOCK_CENTRES
    print(f'  two MGN12H at {BLOCK_CENTRES:.0f} mm centres occupy '
          f'{MGN12H["L"]:.1f} + {BLOCK_CENTRES:.0f} = {span:.1f} mm of rail')
    print('  brief §3 computes usable travel as 300 − 45.4 − 24 = 231 mm, which')
    print('  is the ONE-block figure.  With the two blocks the same brief '
          'mandates:')
    for rail in (300.0, 350.0, 400.0):
        print(f'    {rail:.0f} mm rail → {rail - span:.1f} mm of block travel, '
              f'{rail - span - 24.0:.1f} mm usable after 24 mm of bumpers')

    x100 = [r[1] for r in rows if r[0] == 100][0]
    need_dn = x100 - compression(phi_eq)
    need_up = 100.0 - compression(phi_eq) * 0  # release stations are above eq
    need_ext = compression(phi_eq) - compression(PHI_EXT)
    print(f'\n  Stroke the experiment actually needs, about the equilibrium '
          f'position:')
    print(f'    highest release station, brief §3                 '
          f'+{100.0:6.1f} mm')
    print(f'    knee free to full extension φ = −8° (leg lifted)  '
          f'+{need_ext:6.1f} mm  (inside the above)')
    print(f'    peak compression on the 100 mm drop               '
          f'-{need_dn:6.1f} mm')
    print(f'    → stroke required                                  '
          f'{100.0 + need_dn:6.1f} mm, before bumpers')
    print(f'    → with 12 mm of bumper/crush each end              '
          f'{100.0 + need_dn + 24.0:6.1f} mm')
    for rail in (300.0, 400.0):
        avail = rail - span - 24.0
        ok = 'OK' if avail >= 100.0 + need_dn else 'SHORT by %.1f mm' % (
            100.0 + need_dn - avail)
        print(f'    {rail:.0f} mm rail gives {avail:6.1f} mm usable → {ok}')
    return need_dn


# ------------------------------------------------------------------- dynamics
# Measured off the built Fusion assembly (rig_lib.slide_mass / sprung_split),
# not estimated.  Bare slide, empty ballast pots, no mode pin, 500 g GIM6010-8.
MEASURED = dict(slide_g=1607.6, sprung_g=1051.1, unsprung_g=556.5)


def m_sh_share():
    """The part of the sprung mass that is NOT rigid: none, by definition."""
    return 0.0
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

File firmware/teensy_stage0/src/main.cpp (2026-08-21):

#include <Arduino.h>
#include <FlexCAN_T4.h>
#include <SD.h>
#include <SPI.h>

#if BENI_STAGE0_ENABLE_IMU
#include <Adafruit_BNO08x.h>
#endif

#include "beni_stage0.h"

using beni::stage0::Stage0Record;

namespace {

FlexCAN_T4<CAN1, RX_SIZE_256, TX_SIZE_16> can1;
FlexCAN_T4<CAN2, RX_SIZE_256, TX_SIZE_16> can2;

#if BENI_STAGE0_ENABLE_IMU
Adafruit_BNO08x bno08x(beni::stage0::kBnoResetPin);
sh2_SensorValue_t sensor_value{};
#endif

struct Counters {
  uint32_t can1_tx = 0;
  uint32_t can1_rx = 0;
  uint32_t can2_tx = 0;
  uint32_t can2_rx = 0;
  uint32_t can_errors = 0;
  uint32_t imu_events = 0;
  uint32_t dropped_records = 0;
};

struct ImuLatest {
  int16_t gyro[3] = {};
  int16_t accel[3] = {};
  uint32_t gyro_timestamp = 0;
  uint32_t accel_timestamp = 0;
  bool present = false;
  bool gyro_seen = false;
  bool accel_seen = false;
};

constexpr size_t kRingRecords = 128;
constexpr size_t kWriteRecords = 16;  // 16 * 256 B = one 4 kB SD write.
Stage0Record ring[kRingRecords]{};
size_t ring_head = 0;
size_t ring_tail = 0;
size_t ring_count = 0;

Counters counters;
ImuLatest imu;
File log_file;
bool sd_ready = false;
bool logging = false;
bool sd_write_failed = false;
uint32_t log_started_us = 0;
uint32_t log_bytes = 0;
uint32_t record_sequence = 0;
uint32_t status_flags = 0;
uint32_t can_token = 0;
elapsedMicros sample_clock;
elapsedMicros can_test_clock;
elapsedMillis status_clock;

void print_help() {
  Serial.println("Stage 0 commands:");
  Serial.println("  s  start the 10 minute, 256 kB/s microSD gate");
  Serial.println("  x  stop and close the current microSD test");
  Serial.println("  ?  print status");
  Serial.println("No actuator commands exist in this firmware.");
}

uint32_t elapsed_since(uint32_t then_us) { return micros() - then_us; }

uint32_t flags_now() {
  uint32_t flags = status_flags;
  if (logging) flags |= beni::stage0::kSdActive;
  if (imu.present) flags |= beni::stage0::kImuPresent;
  if (imu.accel_seen) flags |= beni::stage0::kImuRawAccelSeen;
  if (imu.gyro_seen) flags |= beni::stage0::kImuRawGyroSeen;
  return flags;
}

void report_status() {
  Serial.printf(
      "CAN1 tx/rx=%lu/%lu CAN2 tx/rx=%lu/%lu errors=%lu IMU events=%lu "
      "SD=%s bytes=%lu dropped=%lu\n",
      counters.can1_tx, counters.can1_rx, counters.can2_tx, counters.can2_rx,
      counters.can_errors, counters.imu_events, logging ? "ACTIVE" : "idle",
      log_bytes, counters.dropped_records);
}

bool configure_imu_reports() {
#if BENI_STAGE0_ENABLE_IMU
  // The normal accelerometer report is a low-rate keepalive alongside the two
  // raw 1 kHz reports. Only the raw reports are recorded for estimator work.
  const bool accel_keepalive = bno08x.enableReport(SH2_ACCELEROMETER, 10000);
  const bool raw_accel =
      bno08x.enableReport(SH2_RAW_ACCELEROMETER,
                          beni::stage0::kImuReportPeriodUs);
  const bool raw_gyro =
      bno08x.enableReport(SH2_RAW_GYROSCOPE,
                          beni::stage0::kImuReportPeriodUs);
  return accel_keepalive && raw_accel && raw_gyro;
#else
  return false;
#endif
}

void setup_imu() {
#if BENI_STAGE0_ENABLE_IMU
  if (!bno08x.begin_SPI(beni::stage0::kBnoCsPin,
                        beni::stage0::kBnoIntPin)) {
    Serial.println("BNO085 not found; SD and CAN gates remain available.");
    return;
  }
  imu.present = true;
  if (!configure_imu_reports()) {
    Serial.println("BNO085 found, but one or more reports could not be enabled.");
    return;
  }
  Serial.println("BNO085 raw accel/gyro requested at 1 kHz.");
#else
  Serial.println("BNO085 support disabled at compile time.");
#endif
}

void service_imu() {
#if BENI_STAGE0_ENABLE_IMU
  if (!imu.present) return;
  if (bno08x.wasReset() && !configure_imu_reports()) {
    Serial.println("BNO085 reset; report re-enable failed.");
  }
  while (bno08x.getSensorEvent(&sensor_value)) {
    ++counters.imu_events;
    if (sensor_value.sensorId == SH2_RAW_GYROSCOPE) {
      imu.gyro[0] = sensor_value.un.rawGyroscope.x;
      imu.gyro[1] = sensor_value.un.rawGyroscope.y;
      imu.gyro[2] = sensor_value.un.rawGyroscope.z;
      imu.gyro_timestamp = sensor_value.un.rawGyroscope.timestamp;
      imu.gyro_seen = true;
    } else if (sensor_value.sensorId == SH2_RAW_ACCELEROMETER) {
      imu.accel[0] = sensor_value.un.rawAccelerometer.x;
      imu.accel[1] = sensor_value.un.rawAccelerometer.y;
      imu.accel[2] = sensor_value.un.rawAccelerometer.z;
      imu.accel_timestamp = sensor_value.un.rawAccelerometer.timestamp;
      imu.accel_seen = true;
    }
  }
#endif
}

void setup_can() {
  can1.begin();
  can1.setBaudRate(beni::stage0::kCanBaud);
  can2.begin();
  can2.setBaudRate(beni::stage0::kCanBaud);
#if BENI_STAGE0_CAN_INTERNAL_LOOPBACK
  can1.enableLoopBack();
  can2.enableLoopBack();
  Serial.println("CAN1/CAN2 configured for internal loopback at 500 kbit/s.");
#else
#error "Stage 0 must use internal loopback; live-bus transmit is intentionally disabled"
#endif
}

void send_can_test(FlexCAN_T4_Base &bus, uint32_t id, uint32_t token,
                   uint32_t &tx_counter) {
  CAN_message_t message{};
  message.id = id;
  message.len = 8;
  memcpy(message.buf, &token, sizeof(token));
  const uint32_t inverse = ~token;
  memcpy(message.buf + 4, &inverse, sizeof(inverse));
  if (bus.write(message)) {
    ++tx_counter;
  } else {
    ++counters.can_errors;
  }
}
bool valid_can_echo(const CAN_message_t &message, uint32_t expected_id) {
  if (message.id != expected_id || message.len != 8) return false;
  uint32_t token = 0;
  uint32_t inverse = 0;
  memcpy(&token, message.buf, sizeof(token));
  memcpy(&inverse, message.buf + 4, sizeof(inverse));
  return inverse == ~token;
}

void service_can() {
  if (can_test_clock >= 10000) {
    can_test_clock -= 10000;
    ++can_token;
    send_can_test(can1, beni::stage0::kCan1TestId, can_token, counters.can1_tx);
    send_can_test(can2, beni::stage0::kCan2TestId, can_token, counters.can2_tx);
  }

  CAN_message_t message{};
  while (can1.read(message)) {
    if (valid_can_echo(message, beni::stage0::kCan1TestId)) {
      ++counters.can1_rx;
      status_flags |= beni::stage0::kCan1LoopbackOk;
    } else {
      ++counters.can_errors;
    }
  }
  while (can2.read(message)) {
    if (valid_can_echo(message, beni::stage0::kCan2TestId)) {
      ++counters.can2_rx;
      status_flags |= beni::stage0::kCan2LoopbackOk;
    } else {
      ++counters.can_errors;
    }
  }
  can1.events();
  can2.events();
}

bool choose_log_file() {
  char name[16]{};
  for (uint8_t index = 0; index < 100; ++index) {
    snprintf(name, sizeof(name), "STG0_%02u.BIN", index);
    if (!SD.exists(name)) {
      log_file = SD.open(name, FILE_WRITE);
      if (log_file) {
        Serial.printf("Logging to %s\n", name);
        return true;
      }
      return false;
    }
  }
  Serial.println("No free STG0_00.BIN..STG0_99.BIN filename.");
  return false;
}
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

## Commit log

2026-08-17 Snapshot before documentation cleanup (2026-08-17)
    [6010-8????? 20240313.stp, Beni_Prototype1_BASELINE.f3d, Beni_Prototype1_BASELINE.step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]
2026-08-21 Publish current Mode A single-leg build state
    [ABS_FIT_GIM4305_HOUSING.stl, ABS_FIT_GIM4305_OUTPUT.stl, ABS_FIT_GIM6010_HOUSING.stl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]
2026-08-22 Add actuator coupon fit-check guide
2026-08-22 Record actuator coupon fit results
2026-08-22 Add GIM6010 ABS pin-clearance trials
    [ABS_CAL_GIM6010_OUTPUT_PIN_D4p15.stl, ABS_CAL_GIM6010_OUTPUT_PIN_D4p20.stl, ABS_CAL_GIM6010_OUTPUT_PIN_D4p25.stl]
2026-08-23 Add ABS shoulder hub first article
    [ABS_FA_Shoulder_Output_Hub_L_D4p15.stl]
2026-08-23 Verify shoulder plate assembly path
2026-08-23 Record shoulder assembly pass and next fit gates
2026-08-31 Add ABS 6800 bearing bore calibration ladder
    [ABS_CAL_6800_BORE_LADDER.stl]
2026-08-31 Track DigiKey order and single-leg procurement gaps
    [mode_a_procurement_bom_2026-08-21.xlsx]
2026-09-01 Release ABS proximal link with calibrated bearing seats
    [ABS_FA_Proximal_Link_L_D19p10.stl]
2026-09-01 Fix link tangent geometry for stable printing
    [ABS_FA_Proximal_Link_L_D19p10.stl, ABS_FA_Proximal_Link_L_D19p10_PRINT_ORIENTED.stl]
2026-09-01 Put active print queue at top of README
2026-09-01 docs: move print queue below project gallery
2026-09-01 docs: clarify wheel assembly in README gallery
2026-09-02 Redesign proximal link for face-flat printing
    [ABS_FA_Proximal_Link_L_D19p10.stl, ABS_FA_Proximal_Link_L_D19p10_PRINT_ORIENTED.stl]
2026-09-02 Model knee spring as a helical CAD body
2026-09-02 Record proximal bearing fit and ABS build scope
    [mode_a_procurement_bom_2026-08-21.xlsx]
2026-09-03 Add visual shoulder link assembly guide
2026-09-03 Audit printed heat-set insert interfaces
    [mode_a_procurement_bom_2026-08-21.xlsx]
2026-09-03 Redesign printed heat-set interfaces
    [ABS_CAL_PSM_SL_M4_INSERT_POCKET_LADDER_PRINT_ORIENTED.stl, ABS_FA_Chassis_Shoulder_Plate_L_M3_INSERTS_PRINT_ORIENTED.stl, ABS_FA_RIG_Stand_M3_INSERTS_PRINT_ORI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]
2026-09-04 Redesign printed joints for owned heat-set inserts
    [ABS_CAL_OWNED_M4x8_INSERT_POCKET_LADDER_PRINT_ORIENTED.stl, ABS_CAL_PSM_SL_M4_INSERT_POCKET_LADDER_PRINT_ORIENTED.stl, ABS_FA_Shoulder_Output_Hub_L_D4p15.stl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]
2026-09-05 Release coupon-selected M4 ABS hubs and record assembly holds
    [ABS_FA_Shoulder_Output_Hub_L_D4p15_OWNED_M4x8_D5p10_PROVISIONAL_DO_NOT_PRINT.stl, ABS_FA_Shoulder_Output_Hub_L_D4p15_OWNED_M4x8_D5p10_PROVISIONAL_DO_NOT_PRINT_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]
2026-09-06 Fix proximal M4 assembly access and audit adjacent hardware paths
    [ABS_FA_Proximal_Link_L_D19p15_M4_ACCESS_FIXED_PRINT_ORIENTED.stl, ABS_FA_RIG_Cable_Post_A_COVER_MOUNT_PRINT_ORIENTED.stl, Proximal_Link_L.stl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]
2026-09-06 Reconcile ordered 50 mm spring with unadapted cartridge CAD
2026-09-06 Correct received spring length to owner-confirmed 50 mm
    [mode_a_procurement_bom_2026-08-21.xlsx]
2026-09-06 Release supported ABS knee mock-up and detached spring fit caps
    [ABS_MOCKUP_Distal_Link_L_PRINT_ORIENTED.stl, ABS_MOCKUP_Knee_Alignment_Pin_D9p7_PRINT_ORIENTED.stl, ABS_Spring_Seat_Fit_Cap_D8_PRINT_ORIENTED.stl]
2026-09-08 Record successful provisional knee assembly and next ABS fixture steps
2026-09-08 Complete current ABS print queue and close proximal M4 seating hold
2026-09-08 Record four completed ABS prints and remaining single-leg integration work
2026-09-15 Release M3 insert calibration ladder
    [ABS_CAL_OWNED_M3x5_INSERT_POCKET_LADDER_PRINT_ORIENTED.stl]
2026-09-15 Promote Ø4.5 M3 insert receivers
    [ABS_FA_Chassis_Shoulder_Plate_L_M3_INSERTS_PRINT_ORIENTED.stl, ABS_FA_Proximal_Link_L_D19p15_M4_ACCESS_FIXED_PRINT_ORIENTED.stl, ABS_FA_RIG_Stand_M3_INSERTS_PR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]
2026-09-16 Record steel-pin bore failure and release ladder
    [ABS_CAL_KNEE_PIN_BORE_LADDER_PRINT_ORIENTED.stl]
2026-09-17 Correct knee pin coupon to full receiver span
    [ABS_CAL_KNEE_PIN_BORE_LADDER_19MM_PRINTED.stl, ABS_CAL_KNEE_PIN_BORE_LADDER_PRINT_ORIENTED.stl]
2026-09-17 Select 10.30 mm ABS knee pin bore
2026-09-17 Release serviceable ABS distal pin-fit article
    [ABS_FA_Distal_Link_L_D10p30_STEEL_PIN_FIT_PRINT_ORIENTED.stl]
2026-09-17 Release unpowered ABS spring mechanical article
    [ABS_TEST_Cart_Guide_Bar_50mm_FLAT_PRINT_ORIENTED.stl, ABS_TEST_Cart_Lower_Eye_50mm_AXIS_UP_PRINT_ORIENTED.stl, ABS_TEST_Cart_Upper_Eye_50mm_AXIS_UP_PRINT_ORIEN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]
2026-09-18 Clarify spring guide insertion path
2026-09-22 Integrate ordered pins into mechanical assembly
    [ABS_PINREV_Distal_Link_D10p30_D6x10_M4x40_PRINT_ORIENTED.stl, ABS_PINREV_Knee_Stop_Plate_15deg_D6x10_CAPTIVE_PRINT_ORIENTED.stl, ABS_PINREV_Proximal_Link_D19p1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]
2026-09-22 Add ordered pin fit ladders
    [ABS_CAL_D4x10_ROOT_BLIND_SOCKET_LADDER_PRINT_ORIENTED.stl, ABS_CAL_M4x40_CLEVIS_LINK_LAND_LADDER_PRINT_ORIENTED.stl]
2026-09-23 Promote ordered pin fit selections
    [ABS_PINREV_Distal_Link_D10p30_D6x10_M4x40_PRINT_ORIENTED.stl, ABS_PINREV_Knee_Stop_Plate_15deg_D6x10_CAPTIVE_PRINT_ORIENTED.stl, ABS_PINREV_Proximal_Link_D19p1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]
2026-09-23 Record printed pin parts and publish assembly sequence
2026-09-24 Add picture-led ordered-pin assembly guide
2026-09-24 Replace assembly guide with illustrated 21-step Fusion manual
    [build_manual.py]
2026-09-24 partway through correcting the pin interfaces, codex ran out of usage halfway through so this is an incomplete change
    [ABS_PINREV2_Distal_Link_D10p30_D6x10_CLEVIS_D4p30_PRINT_ORIENTED.stl, ABS_PINREV2_Proximal_Link_D19p15_ROOT_D4p30_CLEVIS_D4p30_PRINT_ORIENTED.stl, ABS_PINREV2_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]
2026-09-24 Complete PINREV2 release and assembly readiness
    Finish the interrupted September 23 pin-interface correction:
    - add the missing verified-source hashes so verify_mechanical_release.py
    and CI pass; record the Fusion evidence (live v30 audit, current-source
    rebuild equal to the baseline at Ø4.30, released STLs matching fresh
    exports, mesh-change localization)
    - remove the superseded Sept 22 hub/link files, including the mislabeled
    Ø16 distal, from the release folder
    - recapture the four ordered-pin release images from a fixed iso camera
    and rebuild the manual PDF and page gallery
    - make rig_lib.guarded() restore transforms in finally; a blocked export
    previously left two parts dis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
    [ABS_PINREV_Distal_Link_D10p30_D6x10_M4x40_PRINT_ORIENTED.stl, ABS_PINREV_Proximal_Link_D19p15_ROOT_D4x10_M4x40_PRINT_ORIENTED.stl, ABS_PINREV_Shoulder_Output_H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]
2026-09-24 Make CAD releases machine-independent and clean the rig model
    Fusion 2705.1.25 ignores the STL surface deviation, so the triangle
    fingerprint gate blocked every export on the second machine, and a plain
    High export would have printed the proximal bearing seats 0.040 mm tight.
    - stl_release.py: one print tessellation standard (0.004 mm chord on the
    largest radius, via normal deviation) for rig, spring-test, two-leg and
    coupon exports
    - mesh_fidelity(): prove a mesh is the reviewed B-Rep at its bed pose
    (vertices On the B-Rep, B-Rep samples in the mesh, closed, bed, volume,
    area, chord); assert_export() accepts the pinned fingerprint or this proof
    - exporters retain pinned files that s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
2026-09-25 Clarify heat-set receiver map with numbered Fusion view callouts
2026-09-25 Record physical spring escape and hold spring-installed testing
2026-09-25 Propose fixed-axis knee spring transmission and document audit limitations
2026-09-25 Compare lower-cost active-knee actuators
2026-09-27 Correct the Beni teardown reading from a frame review
    A frame-by-frame review of the 4K teardown footage shows the knee is
    driven from the hip through a hip-coaxial crank and a link to a shin
    lever. The only belts are short 2M stages at each hip, from a
    body-fixed motor to a hip-coaxial ring; no belt runs down the leg.
    The September 25 note had misread the central two-motor body bracket
    as a coaxial hip/knee pair and placed the belt inside the upper leg.
    Rewrite the evidence note with timestamped observations, the verbatim
    belt markings, and what is and is not established. Correct the
    one-line teardown claims in CLAUDE.md, README, PROJECT_STATUS, the R2A
    plan and the legacy guide. Record th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
